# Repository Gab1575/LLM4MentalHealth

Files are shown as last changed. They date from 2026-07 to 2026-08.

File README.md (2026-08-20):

# LLM4MentalHealth

LLM4MentalHealth is a robotics project that explores how non-anthropomorphic social robots can support mental health and wellbeing. The robot embodies a flower that combines petal movement, color, and a dual-stage tendon-driven continuum stem into a single interactive platform.

## Project vision

The flower robot is designed to act as a non-verbal companion that can communicate emotion and intent through:

- five independently addressable petal LEDs,
- four petal-angle actuators,
- a motorized stem / continuum-style drive system,
- a ROS 2-based control interface for real-time command and monitoring.

### Physical layout summary

- Embedded controller: ESP32-based microcontroller running the firmware.
- Communication: Wi-Fi + micro-ROS bridge to a host computer.
- Operator interface: a Tkinter-based GUI and ROS 2 topics.
- Control: servo motors, N20 encoded gear motor, addressable RGB LED NeoPixels.

## Repository structure

- [README.md](README.md): project-level overview and architecture.
- [FullCode_ws](FullCode_ws): host-side ROS 2 workspace, GUI, and message definitions.
- [FullCodeMICROCONTROLLEr](FullCodeMICROCONTROLLEr): embedded firmware for the ESP32-based flower robot.
- [Testing](Testing): hardware and software experiments, prototypes, and validation sketches.
- [Construction](Construction): bill of materials and laser-cut sketches for the physical build.

## Software architecture

The system uses a split architecture:

- A host-side ROS 2 layer publishes high-level commands from the GUI, an optional kinematic solver, and perception nodes.
- A mux node merges those sources into a single authoritative command stream.
- A micro-ROS agent bridges that stream over Wi-Fi to the ESP32.
- The embedded firmware interprets the command stream and drives the robot’s motors, LEDs, and servos.

### Core control flow

1. A user manipulates the GUI, in either manual or kinematic mode.
2. The GUI publishes RobotCommand data to /manual_commands (and, in kinematic mode, bend targets to /kinematic_commands).
3. In kinematic mode, the continuum controller converts those bend targets into per-servo angles and publishes them to /kinematic_calculated_commands.
4. flower_mux selects manual or kinematic data based on /control_mode and publishes one merged RobotCommand to /flower_commands.
5. The micro-ROS agent forwards /flower_commands to the ESP32.
6. The ESP32 updates servo positions, LED colors, and motor target state, and reports debugging information back over /flower_debug.

## ROS node map

```mermaid
flowchart LR
    A["User / Operator"] --> B[flower_gui_node]
    B -->|/manual_commands| M[flower_mux_node]
    B -->|/kinematic_commands| K[continuum_controller_node]
    B -->|/control_mode| M
    K -->|/kinematic_calculated_commands| M
    M -->|/flower_commands| D[micro-ROS Agent]
    D --> E[ESP32 flower_node]
    E --> F[Servo Control]
    E --> G[LED Control]
    E --> H[N20 Motor Control]
    E -->|/flower_debug| J["Foxglove / Debug Tools"]
```

### ROS topics and roles

- /manual_commands, /kinematic_commands, /control_mode
  - Published by flower_gui_node; the raw manual/kinematic operator input and the active mode.

- /kinematic_calculated_commands
  - Published by continuum_controller_node; per-servo angles solved from the kinematic bend targets.

- /flower_commands
  - Custom message type: RobotCommand.
  - Published by flower_mux_node; the single merged command stream (servo angles, LED brightness, LED colors, N20 motor target state) that the embedded firmware actually receives.

- /flower_debug
  - Debug string topic published by the ESP32, used for troubleshooting and runtime telemetry.

### ROS-side components

- flower_gui_node
  - Tkinter-based operator dashboard.
  - Publishes to /manual_commands, /kinematic_commands, and /control_mode.

- continuum_controller_node
  - Kinematic solver; converts bend commands into antagonistic servo-pair angles.

- flower_mux_node
  - Mode-aware multiplexer; merges GUI and kinematic sources into /flower_commands.

- flower.launch.py
  - Launches the micro-ROS agent, Foxglove bridge, GUI, perception nodes, mux, and kinematic controller together.

For the full topic-level breakdown (including the vision/perception nodes), see [FullCode_ws](FullCode_ws).

## Notes

For deeper implementation detail, see the READMEs in the subprojects:

- [FullCode_ws](FullCode_ws)
- [FullCodeMICROCONTROLLEr](FullCodeMICROCONTROLLEr)
- [Construction](Construction)

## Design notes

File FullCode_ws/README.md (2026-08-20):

# FullCode_ws

This workspace is the host-side control stack for the flower robot. It includes the host GUI, ROS2 message definitions, smart command multiplexing, and vision-based position sensing.

## Purpose

The host workspace translates user intent and visual perception into a structured ROS2 command stream for the embedded flower controller. It also provides runtime launch orchestration for camera-based localization and face-tracking perception.

## High-level ROS2 Architecture

The control chain is split into four core domains:

1. **Host UI and command generation**
   - `flower_gui` publishes operator-selected servo, LED, and N20 values.
   - It also publishes kinematic goals and control mode state.

2. **Kinematic solving**
   - `controller` (`continuum_controller_node`) converts `(theta, phi)` bend commands from `/kinematic_commands` into per-servo antagonistic-pair angles.
   - It publishes the resulting `RobotCommand` to `/kinematic_calculated_commands`.

3. **Command multiplexing**
   - `flower_mux` merges GUI state with either manual or kinematic pose commands.
   - It publishes the final `RobotCommand` to `/flower_commands` for the micro-ROS bridge.

4. **Vision-based localization & perception**
   - `localization_tracker` detects red and blue target balls and publishes 3D points to `/vision/red_ball` and `/vision/blue_ball`. These are not currently consumed by any node (see Notes).
   - `face_tracker` publishes a lightweight point representing face pan/tilt angles to `/face_tracking_angles`.

5. **Hardware bridge**
   - `micro_ros_agent` bridges `/flower_commands` from ROS2 into the embedded firmware transport layer.
   - `foxglove_bridge` exposes ROS2 topics for debugging and visualization.

## Workspace files and packages

### Root files

- `flower.launch.py`
  - Launch description for the host stack.
  - Starts `micro_ros_agent`, `foxglove_bridge`, `flower_gui`, `face_tracker`, `localization_tracker`, `flower_mux`, and `continuum_controller`.

### ROS 2 package sources

- `src/flower_gui/`
  - Main host-side control GUI (`flower_gui_node`).
  - Publishes to `/manual_commands`, `/kinematic_commands`, and `/control_mode`.
  - Uses `flower_msgs.msg.RobotCommand` for manual/full-state commands.
  - Uses `std_msgs.msg.Float64MultiArray` for kinematic goal publication.
  - Uses `std_msgs.msg.String` for publishing the selected control mode.
  - Bundles guided breathing routines under `flower_gui/routines/` (e.g. `box_breathing.py`).

- `src/flower_mux/`
  - Smart multiplexer node (`flower_mux_node`).
  - Subscribes to `/manual_commands`, `/kinematic_calculated_commands`, and `/control_mode`.
  - Publishes the merged `RobotCommand` to `/flower_commands`.
  - Ensures time, LED, and N20 payload fields from the GUI remain present in kinematic mode.

- `src/flower_msgs/`
  - Defines the custom `RobotCommand` ROS2 message type.
  - Used by `flower_gui`, `flower_mux`, `controller`, and the embedded controller bridge.

- `src/controller/controller/continuum_controller_node.py`
  - Kinematic solver node. Subscribes to `/kinematic_commands` (`[theta1, phi1, theta2, phi2]`, degrees).
  - Converts each stage's bend into a pair of antagonistic servo angles and publishes `RobotCommand` to `/kinematic_calculated_commands`.
  - Vision-based (red/blue ball) feedback is not currently used by this node.

- `src/ros2-opencv-localization/`
  - Contains the `localization_tracker` node and a camera launch file.
  - Responsible for 3D ball localization from a connected USB camera.

- `src/ros2-opencv-face-tracker/`
  - Contains the face tracker node that publishes face pan/tilt offset angles.
  - Uses a second USB camera for live face detection.

- `src/uros/micro-ROS-Agent/`
  - Contains the micro-ROS agent package used by the host launch file.

## ROS2 Topic & Node Communication Tree

```text
[ Operator ]
      |
      v
flower_gui (host node)
  - publishes /manual_commands         (RobotCommand)
  - publishes /kinematic_commands      (Float64MultiArray)
  - publishes /control_mode            (String)
      |
      +----------------------------------------+
      v                                         v
continuum_controller_node                  flower_mux (host mux node)
  - subscribes /kinematic_commands         - subscribes /manual_commands
  - publishes /kinematic_calculated_commands - subscribes /kinematic_calculated_commands
      |                                       - subscribes /control_mode
      +-------------------------------------->|
                                                - publishes /flower_commands  (RobotCommand)
                                                    |
                                                    v
                                          micro_ros_agent (bridge)
                                                    |
                                                    v
                                    [ Embedded ESP32 / firmware ]

[ Vision & Perception ]
      |
      v
localization_tracker (vision node)
  - publishes /vision/red_ball         (PointStamped)
  - publishes /vision/blue_ball        (PointStamped)
  (not currently subscribed to by any node)

face_tracker (perception node)
  - publishes /face_tracking_angles    (Point)
```

## Simplified Architecture Diagram

```text
[ Operator ]
      |
      v
flower_gui
  publishes /manual_commands  + /kinematic_commands + /control_mode
      |
      +--> continuum_controller_node
      |      subscribes /kinematic_commands
      |      publishes /kinematic_calculated_commands
      |
      v
flower_mux
  selects mode -> merges GUI state with calculated kinematic commands
      |
      v
/flower_commands  ---> micro_ros_agent ---> embedded firmware

[ Vision ]
      |
      +--> localization_tracker
      |      publishes /vision/red_ball
      |               /vision/blue_ball
      |      (USB camera sees red and blue target balls; unused downstream for now)
      |
      +--> face_tracker
             publishes /face_tracking_angles
             (separate camera, face pan/tilt signal)
```

## Topic semantics and data flow

### `/manual_commands` (RobotCommand)
- Published by `flower_gui` continuously.
- Contains the full manual output state from the GUI, including:
  - `servo_angles[4]`
  - `servo_time[4]`
  - `n20_pwm`
  - `n20_target_rotations`
  - `n20_zero`
  - `led_colours_hex[5]`
  - `led_colours_brightness[5]`
- Used as the authoritative state cache in `flower_mux` for both manual and kinematic modes.

### `/kinematic_commands` (Float64MultiArray)
- Published by `flower_gui` from the kinematic control panel.
- Carries `[theta1, phi1, theta2, phi2]` (degrees): bend magnitude and bend-plane direction for each of the two continuum stages.
- Consumed by `continuum_controller_node`.

### `/kinematic_calculated_commands` (RobotCommand)
- Published by `continuum_controller_node`.
- Carries the final per-servo angles (`servo_angles[4]`, all four indices driven) after converting each stage's `(theta, phi)` into an antagonistic servo pair.
- Consumed by `flower_mux`, which merges it with the GUI's cached LED/N20/time state when in kinematic mode.

### `/control_mode` (String)
- Published by `flower_gui` when the UI mode changes.
- Values are `manual` or `kinematic`.
- Controls whether `flower_mux` forwards raw manual state or uses the kinematic-calculated command path.

### `/flower_commands` (RobotCommand)
- Final merged command stream.
- Published by `flower_mux` to the hardware bridge.
- This is the topic the embedded controller ultimately receives via `micro_ros_agent`.

### `/vision/red_ball` and `/vision/blue_ball` (PointStamped)
- Published by `localization_tracker`.
- Each message carries the 3D position of a color-marked ball in camera coordinates.
- Not currently subscribed to by any node; reserved for future vision-based closed-loop control.

### `/face_tracking_angles` (Point)
- Published by `face_tracker`.
- `x` and `y` carry pan and tilt error angles in degrees.
- Intended for face-aligned perception or downstream attention control.

## Physical sensor mapping

### Localization camera
- The `localization_tracker` node uses OpenCV to capture frames from a USB camera.
- It detects red and blue balls using HSV color segmentation.
- It converts ball pixel measurements into 3D coordinates using camera intrinsics (`fx`, `fy`, `cx`, `cy`).
- The two balls define the flower head geometry; this data is not currently consumed by the controller.

### Face-tracker camera
- The `face_tracker` node reads from an attached camera and detects the closest face using RetinaFace.
- It publishes a minimal steering signal as pan/tilt error angles.
- This is useful for adding a second perception channel for attention-based interaction.

### Embedded hardware connection
- `micro_ros_agent` runs as a bridge node in `flower.launch.py`.
- It exposes host-side `RobotCommand` traffic to the ESP32/microcontroller transport layer.
- The controller receives the final merged `/flower_commands` message rather than raw GUI-only messages.

## File summary

### `src/flower_gui/`
- Primary host control UI (`flower_gui_node`).
- Publishes manual and kinematic command streams.
- Saves GUI state to `~/flower_gui_settings.json`.
- Uses `flower_msgs.msg.RobotCommand`.

### `src/flower_mux/`
- Smart mode-dependent message multiplexer (`flower_mux_node`).
- Ensures kinematic mode keeps the GUI's latest LED and N20 state.
- Sends one coherent `RobotCommand` stream to hardware.

### `flower.launch.py`
- Host-side launch orchestration.
- Starts the GUI, the vision nodes, the kinematic controller, `flower_mux`, `micro_ros_agent`, and `foxglove_bridge` together.

### `src/flower_msgs/msg/RobotCommand.msg`
- Defines the host-to-hardware command schema.
- Ensures consistent message structure across GUI, mux, controller, and firmware.

### `src/controller/controller/continuum_controller_node.py`
- Kinematic solver: converts `(theta, phi)` bend commands into antagonistic servo-pair angles.
- Subscribes to `/kinematic_commands`; publishes `/kinematic_calculated_commands`.

### `src/ros2-opencv-localization/`
- Contains the camera-based localization tracker.
- Publishes `/vision/red_ball` and `/vision/blue_ball`.

### `src/ros2-opencv-face-tracker/`
- Contains the face tracker node.
- Publishes `/face_tracking_angles`.

## Notes

- `flower_gui`, `flower_mux`, and `controller` are all standard `ament_python` packages under `src/`, built with `colcon build` and run via `ros2 run <package> <executable>` (or through `flower.launch.py`).
- The root launch file currently starts the perception and control bridge nodes, but the embedded controller node may require a separate launch or firmware-side startup.

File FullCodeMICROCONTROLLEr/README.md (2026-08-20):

# FullCodeMICROCONTROLLEr

This project is the embedded firmware for the flower robot. It runs on an ESP32 controller and is responsible for receiving commands from ROS 2, driving the physical actuators, and maintaining the robot’s real-time behavior.

## Purpose

The firmware implements the robot’s low-level control layer. Its responsibilities are:

- establishing Wi-Fi connectivity for micro-ROS communication,
- receiving RobotCommand payloads from the host workstation,
- updating the servo-driven petal positions,
- driving petal LEDs with color and brightness values,
- controlling the N20 motor and encoder-based position loop,
- publishing debug telemetry back over ROS for troubleshooting.

## High-level architecture

The firmware is organized around a simple control loop:

1. Initialize Wi-Fi and the micro-ROS transport.
2. Initialize the hardware subsystems: LEDs, servos, and motor.
3. Wait for incoming RobotCommand messages.
4. Apply the new command state each loop iteration.
5. Update hardware outputs and publish debug information.

## Folder and file overview

### Root files

- platformio.ini
  - PlatformIO configuration for building and uploading the firmware.
  - Defines dependencies and board settings for the ESP32 target.

### include/

The include directory contains shared declarations and hardware abstractions.

- MicroRos.h
  - Central header for ROS-related globals, data structures, and function declarations.
  - Defines the shared Data struct that holds servo, LED, and N20 command state.

- N20.h
  - Pin definitions, constants, and function declarations for the N20 motor.

- petal_lights.h
  - LED subsystem declarations.

- servo_control.h
  - Servo subsystem declarations and constants.

- MicroRosWifiCredentialsEXAMPLE.h
  - Example template for storing Wi-Fi credentials locally.

### src/

The source directory contains the actual implementation of the firmware logic.

- main.cpp
  - Main application entry point.
  - Performs startup initialization and runs the main control loop.

- MicroRos.cpp
  - Implements Wi-Fi setup, micro-ROS initialization, message subscription, and debug publishing.

- servo_control.cpp
  - Implements servo initialization and motion control.

- petal_lights.cpp
  - Implements LED rendering and color updates.

- N20.cpp
  - Implements encoder-based position tracking and motor control.

## Deep dive by file

### src/main.cpp

This is the orchestrator for the firmware.

Responsibilities:

- initializes serial logging,
- sets up Wi-Fi,
- initializes LED control,
- initializes servo control,
- initializes the N20 motor,
- calls the micro-ROS setup routine,
- enters the main loop where each subsystem is refreshed from the latest command state.

Main loop behavior:

- processes pending ROS callbacks,
- updates each petal LED from the current command data,
- applies the latest servo target positions,
- updates the N20 motor position estimate and control loop,
- shows the new LED output.

### src/MicroRos.cpp

This file is the embedded ROS bridge.

Its main functions are:

- WiFiSetup()
  - Connects the ESP32 to Wi-Fi.
  - Resolves the host agent hostname using mDNS.
  - Configures the micro-ROS transport.

- MicroRosSetup()
  - Initializes the ROS 2 node, executor, subscription, and debug publisher.
  - Subscribes to the /flower_commands topic.

- subscription_callback()
  - Receives incoming RobotCommand data.
  - Copies the servo angles, N20 target, N20 speed, LED colors, and brightness values into the shared global data struct.

- send_debug()
  - Formats and publishes debug strings to the /flower_debug topic.

This module is the critical link between the host system and the physical hardware.

### src/servo_control.cpp

This file manages the stem's tendon-driven bend, via the four servos that remain
after the neck joint (the former servo 0) was removed from the design.

Key responsibilities:

- initialize the PCA9685 servo driver over I2C,
- track each servo's current/target pulse and move it smoothly (S-curve eased) toward
  the target over a commanded time window,
- expose absolute angle targets (-90 to 90 degrees) to the rest of the firmware.

Servos 0-3 map directly to PCA9685 channels 0-3 (`ServoState.hardwareIndex`).

### src/petal_lights.cpp

Responsibilities:

- create and manage an LED array,
- update individual petal colors from incoming command values,
- scale each LED’s brightness,
- push the color values to the physical LEDs.

The implementation uses FastLED and a CRGB buffer. It updates the LED state in memory first and only shows the result once the full frame is prepared.

### src/N20.cpp

This file controls the N20 geared motor and its feedback loop.

Responsibilities:

- configure motor control pins,
- initialize encoder input pins,
- attach an interrupt service routine for encoder pulses,
- track motor position in rotations,
- apply a simple control loop that moves the motor toward the commanded target.

Key functions:

- n20EncoderISR()
  - Reads the encoder state and updates the tick count.

- n20MotorBegin()
  - Initializes the hardware and synchronizes the internal position estimate with the commanded target.

- n20MotorSetSpeed()
  - Applies PWM speed control.

- n20MotorSetDirection()
  - Sets the motor direction through the H-bridge pins.

- n20MotorControl()
  - Compares the current position to the target and drives the motor until it is within tolerance.

- n20MotorPosition()
  - Converts encoder ticks into a position estimate for the control loop.

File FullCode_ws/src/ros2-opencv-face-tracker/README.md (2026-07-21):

# ROS 2 OpenCV Face Tracker: Zero-Latency Edge Perception 





A hyper-optimized, real-time computer vision node for ROS 2 that achieves zero-latency face tracking by bypassing standard middleware serialization bottlenecks.

## 📖 Project Overview

In standard ROS 2 perception pipelines, relying on generic camera drivers and `CvBridge` introduces severe frame-rate drops on standard edge hardware (often sub-1 FPS). This is caused by the heavy network serialization overhead of translating massive raw image matrices into ROS network messages and back again.

This package re-architects the perception pipeline into a lightweight, all-in-one edge node. By utilizing OpenCV's direct hardware interface (`cv2.VideoCapture`) to pull frames straight into the processing script, this node keeps heavy image matrices entirely off the ROS local network. The result is flawless, real-time bounding box tracking that leaves maximum CPU overhead available for downstream robotic control.

## ✨ Key Features

* **Zero-Latency Processing:** Bypasses `usb_cam` and `CvBridge` serialization, reading the hardware stream directly.
* **Optimized Haar Cascades:** Fine-tuned detection parameters (`scaleFactor=1.3`, `minNeighbors=5`) to maximize frames per second without sacrificing accuracy.
* **Dynamic Contrast Adjustment:** Integrates CLAHE (Contrast Limited Adaptive Histogram Equalization) to maintain robust tracking in poor or uneven lighting conditions.
* **Native GUI Rendering:** Utilizes lightweight `cv2.imshow` native windows instead of heavy ROS debugging GUIs (like `rqt`) to eliminate rendering bottlenecks.

## ⚙️ System Requirements

* **OS:** Ubuntu 22.04 LTS
* **Middleware:** ROS 2 Humble Hawksbill
* **Dependencies:** Python 3, OpenCV (`python3-opencv`), `cv_bridge`, `sensor_msgs`
* **Hardware:** Any standard USB Web Camera (tested on `/dev/video*`)

## 🛠️ Installation & Build Instructions

1. **Clone the repository into your ROS 2 workspace:**
   ```bash
   cd ~/your_ws/src
   git clone [https://github.com/abinaabey2006/ros2-opencv-face-tracker.git](https://github.com/abinaabey2006/ros2-opencv-face-tracker.git)

    Navigate to the workspace root and resolve dependencies:
    Bash

    cd ~/your_ws
    rosdep install --from-paths src --ignore-src -r -y

    Build the package:
    Bash

    colcon build --packages-select face_tracker

    Source the workspace:
    Bash

    source install/setup.bash

🚀 Usage

To launch the real-time tracking node, ensure your USB camera is plugged in and run:
Bash

ros2 run face_tracker face_tracker

A native OpenCV window will open displaying the real-time camera feed with a tracking bounding box.

    Note: To cleanly exit the node and release the camera hardware, press Ctrl+C in the terminal.

🔮 Future Scope: Autonomous Motion Control

The current architecture successfully isolates and tracks targets at the edge. The immediate next step for this project is to publish the (x, y) center coordinates of the detected bounding box as lightweight geometry_msgs/Point or geometry_msgs/Pose data.

This will act as the foundational perception data to drive autonomous motion control systems—allowing physical platforms (like a TurtleBot 3 in Gazebo) to execute trajectory adjustments to keep the target dynamically centered in its field of view.

Built by Abina Abey.

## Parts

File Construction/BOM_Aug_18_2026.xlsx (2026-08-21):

FlowerAssembly
Working BOM | as of August 18, 2026 at 6:11:39 PM UTC
 | Gavin.Bayley@queensu.ca
INDIVIDUAL COUNTS |  |  |  |  | TOTAL COUNTS
Section | Part Name | Description | Quantity | Material | Part Name | Description | Quantity | Material
Flower Head |  |  |  |  | 0.1uF Cap | Small Cap next to ESP32 Power Pins | 1 | Electrical Component
 | BaseV3 | Central Component | 1 | Resin (MSLA Printer) | 1.2mm Spring Steel Rod | Back Bone | 1 | Spring Steel | https://www.amazon.ca/BBYPP-Straight-Steeless-Assortment-Different/dp/B09DKG7MNB
 | CenterRingV3 | 2 Bodies, Structure & Shell. Print seperatly. Holes drilled to 2mm for Pins | 1 | Resin (MSLA Printer) | 1000uF Cap | Large Cap next to power in of Perfboard | 1 | Electrical Component
 | BlueBall | For Localization | 1 | PLA (FDM Printer) | 3 wire conductor | 3 wire conductor for LED's in ft | 1 | Electrical Component | https://www.digikey.ca/en/products/detail/tensility-international-corp/30-00495/13617532?gclsrc=aw.ds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
 | 3mmx50mm rod | Cut Stainless Steel Rod, Supports Balls | 2 | Steel | 3x12mm Rod | Pins for OuterBearings | 8 | Steel | https://www.amazon.ca/Awclub-Stainless-Industry-Working-Hobbies/dp/B0CN79F664?sp_csd=d2lkZ2V0TmFtZT1zcF9hdGY
 | FlowerPetal | Flower Petals, Holes drilled to 2mm | 5 | Resin (MSLA Printer) | 3x18mm Rod | Holds assembly Together and supports Bearing | 12 | Steel
 | RedBall | For Localization | 1 | PLA (FDM Printer) | 3x50mm rod | Cut Stainless Steel Rod, Supports Balls | 2 | Steel
 | 4x30mm rod | Cut Stainless Steel Rod, Centering Rods for CentreRingV3 | 3 | Steel | 3x8mm Rod | Pins for inner bearings | 8 | Steel
 | ConnectingBracketV3 | Connecting Rods Between Flower Petal and Center Ring. Holes Drilled to 2mm for Pins | 5 | Resin (MSLA Printer) | 4x30mm rod | Cut Stainless Steel Rod, Centering Rods for CentreRingV3 | 3 | Steel | https://www.amazon.ca/PATIKIL-Marine-Stainless-Support-Shelves/dp/B0FWKMY94L
 | 4x6mm Brass Sleeve | Sleeve for reduced friction on centering rods | 3 | Brass | 4x6mm Brass Sleeve | Sleeve for reduced friction on centering rods | 3 | Brass | https://www.amazon.ca/MECCANIXITY-Bearings-Self-Lubricating-Movements-Machinery/dp/B0FFS8BSXX
 | M6x6 Heat Set Insert | Placed in CenterRingV3 | 1 | Brass | 7 Conductor Cable | Wiring between flower head and pot (ft) | 2 | Electrical Component | https://www.digikey.ca/en/products/detail/tensility-international-corp/30-00516/24671340?gclsrc=aw.ds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
 | Socket Head Cap Screw M1.6x0.35 x 4 | N20 Motor Screws | 2 | Steel | Aluminum Cable Ferrules, 0.02" | Crimps to tie Tendon Ends | 16 | Aluminum | https://www.amazon.ca/uxcell-Aluminum-Crimping-Ferrules-Ferrule/dp/B0F8R57K5M
 | MicroGearmotor v3 | 300RPM 6V N20 GearMotor | 1 | Brass, Soft Yellow | Ball and Socket | Middle Joints | 6 | Resin (MSLA Printer)
 | ws2812 5050 led | LED's for the Flower Petals | 5 | Electrical Component | Ball and Socket - 4mm | Lower Joints Gradually Grow to connection with Base | 1 | Resin (MSLA Printer)
 | 3 wire conductor | 3 wire conductor for LED's in ft | 1 | Electrical Component | Ball and Socket - 5mm | "" | 1 | Resin (MSLA Printer)
 | JST1.5 6 pin connector male | Connector for N20 Motor | 1 | Electrical Component | Ball and Socket - 6mm | "" | 1 | Resin (MSLA Printer)
 | JST1.5 3 pin connector | Male and Female for connector for LED string | 1 | Electrical Component | Ball and Socket - 7mm | "" | 1 | Resin (MSLA Printer)
 | Pin | Cut 2x8mm Stainless Steel Rod. Attaches Connecting Rod to both Petals and CenterRing | 10 | Steel | Ball and Socket - 8mm | "" | 1 | Resin (MSLA Printer)
Stem |  |  |  |  | Ball and Socket Top | Top Piece | 1 | Resin (MSLA Printer)
 | Ball and Socket | Middle Joints | 6 | Resin (MSLA Printer) | Barrel Jack | Power Jack | 1 | Electrical Component
 | Ball and Socket Top | Top Piece | 1 | Resin (MSLA Printer) | BarrelJackMount | Part to hold the barrel Jack | 1 | PLA (FDM Printer)
 | Ball and Socket - 4mm | Lower Joints Gradually Grow to connection with Base | 1 | Resin (MSLA Printer) | BasePlate | Laser cut base plate | 1 | 3mm Acrylic | https://www.amazon.ca/dp/B088LM5PCG?amp=
 | Ball and Socket - 7mm | "" | 1 | Resin (MSLA Printer) | BaseV3 | Central Component | 1 | Resin (MSLA Printer)
 | Ball and Socket - 8mm | "" | 1 | Resin (MSLA Printer) | Bearing | Bearings | 24 | Steel | https://www.amazon.ca/Saipor-693ZZ-Bearings-Bearing-Miniature/dp/B0DHNJ51PH?sp_csd=d2lkZ2V0TmFtZT1zcF9hdGY
 | Ball and Socket - 5mm | "" | 1 | Resin (MSLA Printer) | Binding Head Screw M3x5 | Screws to affix SpoolV2 to Servo Horn | 2 | Steel
 | Ball and Socket - 6mm | "" | 1 | Resin (MSLA Printer) | BlueBall | For Localization | 1 | PLA (FDM Printer)
 | 1.2mm Spring Steel Rod | Back Bone | 1 | Spring Steel | CenterRingV3 | 2 Bodies, Structure & Shell. Print seperatly. Holes drilled to 2mm for Pins | 1 | Resin (MSLA Printer)
 | Stainless Steel Cable, 1x7, 0.021" | Tendons. Each approx 1.5ft. | 8 | Steel | CentreSupport | 3D Printed Center Support | 1 | PLA (FDM Printer)
 | Aluminum Cable Ferrules, 0.02" | Crimps to tie Tendon Ends | 16 | Aluminum | ConnectingBracketV3 | Connecting Rods Between Flower Petal and Center Ring. Holes Drilled to 2mm for Pins | 5 | Resin (MSLA Printer)
Base |  |  |  |  | ESP-32 | Microcontroller | 1 | Electrical Component | https://www.amazon.ca/ESP-WROOM-32-NodeMCU-Bluetooth-Development-Microcontroller/dp/B0CHBMFJBQ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
Servo Assembly (x4) |  |  |  |  | ElectronicsPlate | Laser Cut plate that Electronics mount to | 1 | 3mm Acrylic
 | ServoPlate | Plates that Servos Mount on | 1 | 3mm Acrylic | FlowerPetal | Flower Petals, Holes drilled to 2mm | 5 | Resin (MSLA Printer)
 | Nylon Washer - M2.5 | Nylon Washers For Spring and ServoTensioner Affixment | 4 | Nylon | HeatSetInsert-M2.5x2.5 | To affix ServoPlate to ServoTensioner | 2 | Brass
 | Nylon Washer - M3 | Nylon Washers for Servo Affixment | 4 | Nylon | HeatSetInsert-M2.5x4 | Insert for Spring | 1 | Brass
 | Stainless Steel Washer - M3 | Steel Washers for Servo Affixment | 4 | Steel | HeatSetInsert-M2.5x6 | Inserts for Mounting | 3 | Brass
 | ServoTensioner | Component that allows for the assembly to be tensioned | 1 | PLA (FDM Printer) | HeatSetInsert-M3x8 | Heat Set Insert for Servo Tensioner | 1 | Brass
 | HeatSetInsert-M2.5x2.5 | To affix ServoPlate to ServoTensioner | 2 | Brass | JST1.5 3 Pin Connector | Male and Female for connector for LED string | 1 | Electrical Component
 | SpoolV2 | Wire Spool | 1 | Resin (MSLA Printer) | JST1.5 6 pin connector male | Connector for N20 Motor | 1 | Electrical Component
 | ServoHorn | Metal Circular Servo Horn Included with Servos | 1 | Steel | L293D H bridge Motor Driver | Motor Driver for N20 Motor | 1 | Electrical Component | https://www.digikey.ca/en/products/detail/stmicroelectronics/L293D/634700?gclsrc=aw.ds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
 | Spring-4mmx10 | Spring for Tensioning | 1 | Steel | M2.5 Nut | Nut to affix Spring | 21 | Steel
 | ServoMotorBrushless | Servo Motor | 1 | Electrical Component | M2.5 Nylon Washer | Nylon Washers For Spring and ServoTensioner Affixment | 39 | Nylon | https://www.amazon.ca/1205PCS-Nylon-Flat-Washers-Assortment/dp/B0FRMRXMQR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
 | Socket Head Screw - M3x0.5 x 12 | Screws to Fasten Servo Motor | 4 | Steel | M3 Nut | Nuts to Fasten Servo Motor | 11 | Steel
 | Hexagon Nut - M3 x 0.5 | Nuts to Fasten Servo Motor | 4 | Steel | M3 Nylon Washer | Nylon Washers for Servo Affixment | 22 | Nylon
 | HeatSetInsert-M3x8 | Heat Set Insert for Servo Tensioner | 1 | Brass | M6x6 Heat Set Insert | Placed in CenterRingV3 | 1 | Brass
 | Socket Head Screw - M2.5x0.45 x 6 | Screws to Fasten Servo Tensioner and Spring | 3 | Steel | MicroGearmotor v3 | 300RPM 6V N20 GearMotor | 1 | Brass, Soft Yellow
 | Hexagon Nut - M2.5 x 0.45 | Nut to affix Spring | 1 | Steel | MidBearingMount-Bottom | Plate for middle sections | 3 | 3mm Acrylic
 | Binding Head Screw - M3x5 | Screws to affix SpoolV2 to Servo Horn | 2 | Steel | MidBearingMount-Mid | Plate that has bearing pin slots for middle section | 1 | 3mm Acrylic
 | Socket Head Screw - M3x0.5 x 5 | Screw to affix ServoHorn to ServoMotor | 1 | Steel | MidPlate | Lower Assembly Plate | 1 | 3mm Acrylic
Side Supports (x4) - 1 Modified |  |  |  |  | MidPlateShell | Outer Acrylic | 3 | 3mm Acrylic
 | HeatSetInsert-M2.5x6 | Inserts for Mounting | 3 | Brass | MidPlateShellBearing | Outer Acrylic with bearing shaft holes | 1 | 3mm Acrylic
 | HeatSetInsert-M2.5x4 | Insert for Spring | 1 | Brass | OuterShell | Case For Flower Pot | 1 | PLA (FDM Printer)
 | SideSupports | Support to hold Servo Assemblies | 1 | PLA (FDM Printer) | PCA9685 | Servo Motor Controller | 1 | Electrical Component | https://www.amazon.ca/PCA9685-Automation-Robotics-Development-Generator/dp/B0G2SXDK4X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
 | SideSupportWire | Support to hold Servo Assemblies -> 1x needed for wire passthrough | 1 | PLA (FDM Printer) | Perfboard | Mounts Motor Driver and ESP32 and gives pinouts/ins for components | 1 | Perfboard
 | Socket Head Screw M2.5x0.45 x 4 | Screw to affix Spring | 1 | Steel | Pin | Cut 2x8mm Stainless Steel Rod. Attaches Connecting Rod to both Petals and CenterRing | 10 | Steel
Plates Assembly (x1) |  |  |  |  | Pinhole Camera | Ultra Tiny USB Webcam Camera with GC0307 Sensor | 2 | Electrical Component | https://www.digikey.ca/fr/products/detail/adafruit-industries-llc/5733/21839820
 | MidBearingMount-Mid | Plate that has bearing pin slots for middle section | 1 | 3mm Acrylic | RedBall | For Localization | 1 | PLA (FDM Printer)
 | TopPlate | Top Plate | 1 | 3mm Acrylic | Rollers | Horizontal bearing sleeves | 8 | PLA (FDM Printer)
 | 3x18mm Rod | Holds assembly Together and supports Bearing | 12 | Steel | ServoHorn | Metal Circular Servo Horn Included with Servos | 1 | Steel
 | 3x8mm Rod | Pins for inner bearings | 8 | Steel | ServoMotorBrushless | Servo Motor | 1 | Electrical Component | https://www.digikey.ca/en/products/detail/dfrobot/SER0062/18069235?gclsrc=aw.ds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
 | Bearing | Bearings | 24 | Steel | ServoPlate | Plates that Servos Mount on | 1 | 3mm Acrylic
 | SmallBearingSleeve | Vertical Bearing Sleeves | 16 | Steel | ServoTensioner | Component that allows for the assembly to be tensioned | 1 | PLA (FDM Printer)
 | MidBearingMount-Bottom | Plate for middle sections | 3 | 3mm Acrylic | SideSupportWire | Support to hold Servo Assemblies -> 1x needed for wire passthrough | 1 | PLA (FDM Printer)
 | MidPlate | Lower Assembly Plate | 1 | 3mm Acrylic | SideSupports | Support to hold Servo Assemblies | 1 | PLA (FDM Printer)
 | 3x12mm Rod | Pins for OuterBearings | 8 | Steel | SmallBearingSleeve | Vertical Bearing Sleeves | 16 | Steel
 | MidPlateShell | Outer Acrylic | 3 | 3mm Acrylic | Socket Head Screw M1.6x4 | N20 Motor Screws | 2 | Steel
 | MidPlateShellBearing | Outer Acrylic with bearing shaft holes | 1 | 3mm Acrylic | Socket Head Screw M2.5x4 | Screw to affix Spring | 1 | Steel
 | Rollers | Horizontal beraing sleeves | 8 | PLA (FDM Printer) | Socket Head Screw M2.5x6 | Screws to Fasten Servo Tensioner and Spring | 3 | Steel
 | Socket Head Screw M3x0.5 x 25 | Outer Assembly Screws | 4 | Steel | Socket Head Screw M2.5x8 | misc screws | 19 | Steel
 | Nylon Washer M3 | Nylon Washers | 14 | Nylon | Socket Head Screw M3x12 | Screws to Fasten Servo Motor | 4 | Steel
 | Nut M3 x 0.5 | Nuts | 7 | Steel | Socket Head Screw M3x20 | Inner Mid Plate Screws | 3 | Steel
 | Pinhole Camera | Ultra Tiny USB Webcam Camera with GC0307 Sensor | 1 | Electrical Component | Socket Head Screw M3x25 | Outer Assembly Screws | 4 | Steel
 | Socket Head Screw M3x0.5 x 20 | Inner Mid Plate Screws | 3 | Steel | Socket Head Screw M3x30 | Tensioning Screws | 4 | Steel
Electronrics Assembly |  |  |  |  | Socket Head Screw M3x5 | Screw to affix ServoHorn to ServoMotor | 1 | Steel
 | Perfboard | Mounts Motor Driver and ESP32 and gives pinouts/ins for components | 1 | Perfboard | SpoolV2 | Wire Spool | 1 | Resin (MSLA Printer)
 | 1000uF Cap | Large Cap next to power in of Perfboard | 1 | Electrical Component | Spring-4mmx10 | Spring for Tensioning | 1 | Steel
 | 0.1uF Cap | Small Cap next to ESP32 Power Pins | 1 | Electrical Component | Stainless Steel Cable, 1x7, 0.021" | Tendons. Each approx 1.5ft. | 8 | Steel
 | ESP-32 | Microcontroller | 1 | Electrical Component | Stainless Steel Washer - M3 | Steel Washers for Servo Affixment | 4 | Steel
 | L293D H bridge Motor Driver | Motor Driver for N20 Motor | 1 | Electrical Component | Standoff m2.5x24mm | Flower Pot Legs | 4 | Plastic
 | ElectronicsPlate | Laser Cut plate that Electronics mount to | 1 | 3mm Acrylic | Standoff m2.5x8mm | Standoff between base plate and electronics plate | 1 | 3mm Acrylic
 | PCA9685 | Servo Motor Controller | 1 | Electrical Component | TopPlate | Top Plate | 1 | 3mm Acrylic
 | BarrelJackMount | Part to hold the barrel Jack | 1 | PLA (FDM Printer) | ws2812 5050 led | LED's for the Flower Petals | 5 | Electrical Component | https://www.digikey.ca/en/products/detail/w%C3%BCrth-elektronik/1315050930002/22677876
 | Barrel Jack | Power Jack | 1 | Electrical Component
 | Standoff m2.5x24mm | Flower Pot Legs | 4 | Plastic
 | Standoff m2.5x8mm | Standoff between base plate and electronics plate | 1 | 3mm Acrylic
 | M2.5 Nut | Misc nuts | 13 | Steel
 | M2.5 Nylon Washer | Misc Washers | 13 | Nylon
 | M.25x8 Socket Head Screw | misc screws | 7 | Steel
MISC
 | Nylon Washer M2.5 | Misc Nylong Washers | 22 | Nylon
 | Socket Head Screw - M2.5x0.45 x 8 | Misc Screws | 12 | Steel
 | CentreSupport | 3D Printed Center Support | 1 | PLA (FDM Printer)
 | Nylon Washer M3 | Washers for tensioning Screws | 4 | Nylon
 | 7 Conductor Cable | Wiring between flower head and pot (ft) | 2 | Electrical Component
 | OuterShell | Case For Flower Pot | 1 | PLA (FDM Printer)
 | BasePlate | Laser cut base plate | 1 | 3mm Acrylic
 | Socket Head Screw - M3x0.5 x 30 | Tensioning Screws | 4 | Steel
 | Nut M2.5 | Nuts | 7 | Steel
 | Pinhole Camera | Ultra Tiny USB Webcam Camera with GC0307 Sensor | 1 | Electrical Component

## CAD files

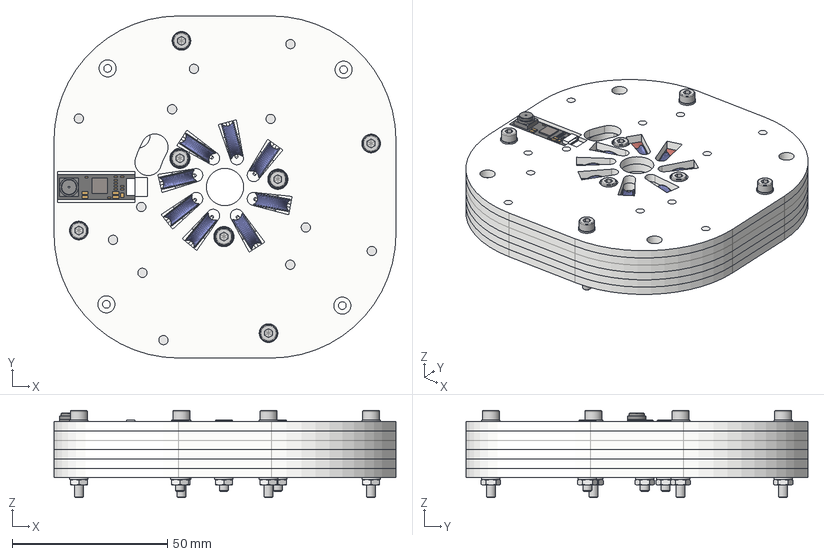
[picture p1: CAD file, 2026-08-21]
Construction/Fusion360Export/Current/Bases/BaseV7/Assemblies/PlatesAssembly_v33.step
110.0 x 110.0 x 28.0 mm
3x18mm Rod x 12
TopPlate
MidBearingMount-Mid
3x8mm Rod x 9
BearingSleeve x 16
MidBearingMount-Bottom x 3
MidPlate
MidPlateShell x 3
MidPlateShellBearing
3x10mm Rod x 8
Bearing_9
BearingSleeve_1 x 8
Bearing_10
Bearing_11
Bearing_12
Bearing_13
Bearing_14
Bearing_15
Bearing_16
Bearing_17
Bearing_18
Bearing_19
Bearing_20
Bearing_21
Bearing_22
Bearing_23
Bearing_24
BW BS 4320 - M3 E Steel 100 HV Plain x 14
BSHCS ASME B18.3.1M - M3x0.5 x 25 Steel Grade 2 Plain x 4
DIN 439-2 - M3 x 0.5 Steel 6 Plain x 7
BSHCS ASME B18.3.1M - M3x0.5 x 20 Steel Grade 2 Plain x 3
SmallBearingSleeve x 16
Ultra Tiny USB Camera with GC0307 Sensor

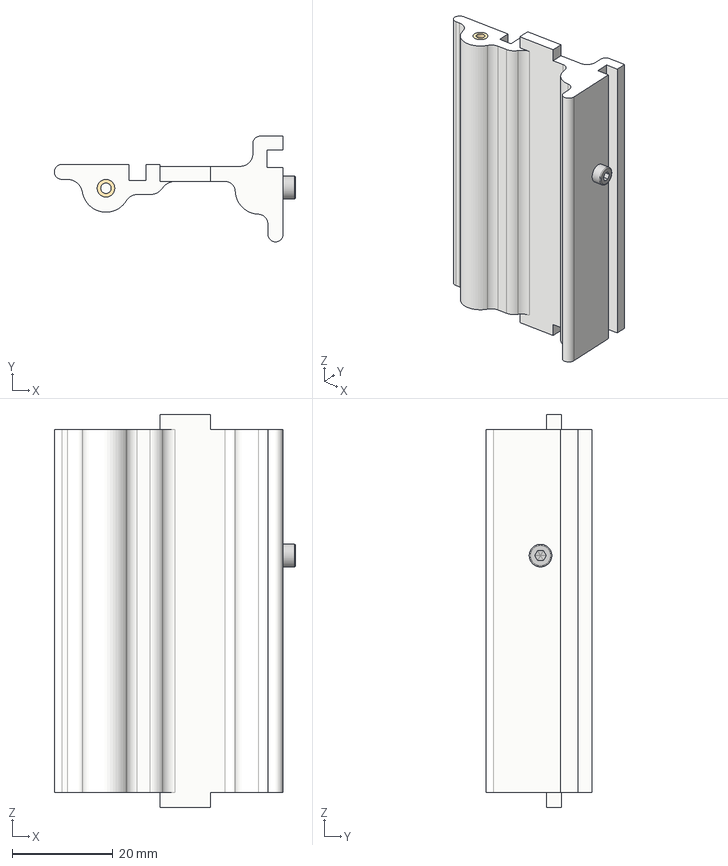
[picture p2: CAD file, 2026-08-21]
Construction/Fusion360Export/Current/Bases/BaseV7/Assemblies/SlideSupportAssembly_v5.step
47.9 x 21.0 x 78.0 mm
HeatSetInsert-M2.5x6 x 3
SlideSupports
HeatSetInsert-M2.5x4
BSHCS ASME B18.3.1M - M2.5x0.45 x 4 Steel Grade 2 Plain

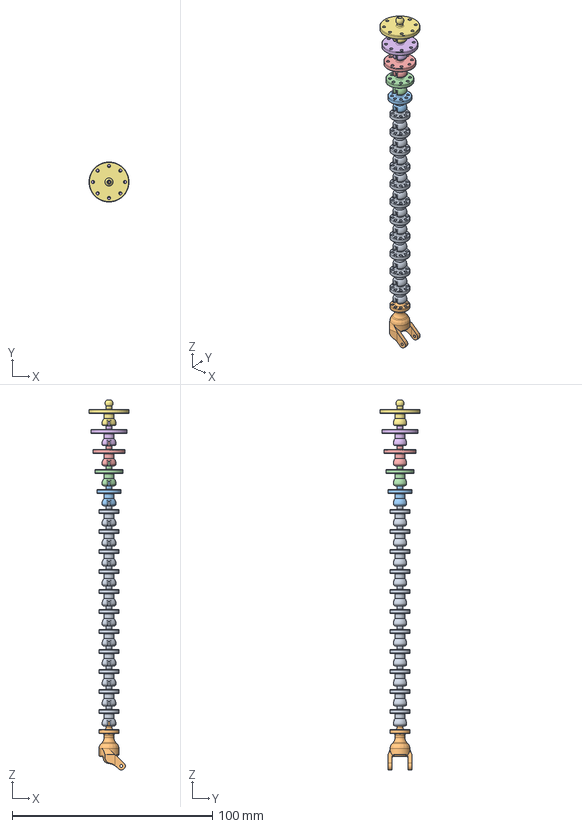
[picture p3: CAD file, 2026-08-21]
Construction/Fusion360Export/Current/Stems/ContinuumStemV4/Assembly_v6.step
20.0 x 20.0 x 184.9 mm
Ball and Socket x 11
Ball and Socket Top
Ball and Socket - 4mm
Ball and Socket - 5mm
Ball and Socket - 6mm
Ball and Socket - 7mm
Ball and Socket - 8mm

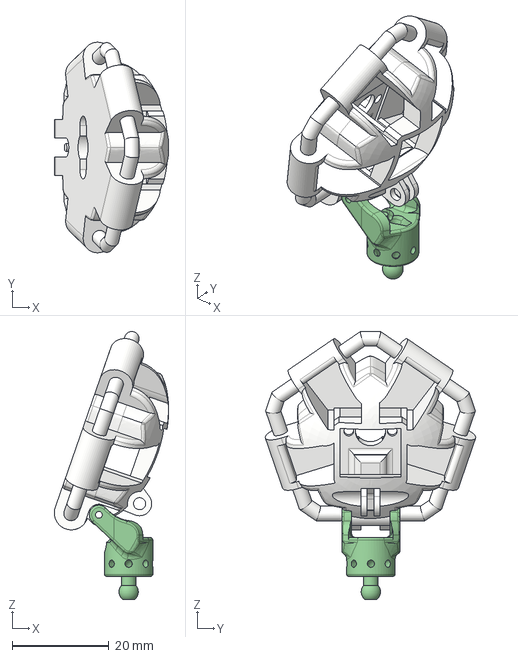
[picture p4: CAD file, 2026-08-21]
Construction/Fusion360Export/Current/Stems/ContinuumStemV4/TopAssembly_v10.step
23.6 x 43.5 x 55.4 mm
Ball and Socket Top
BaseV3

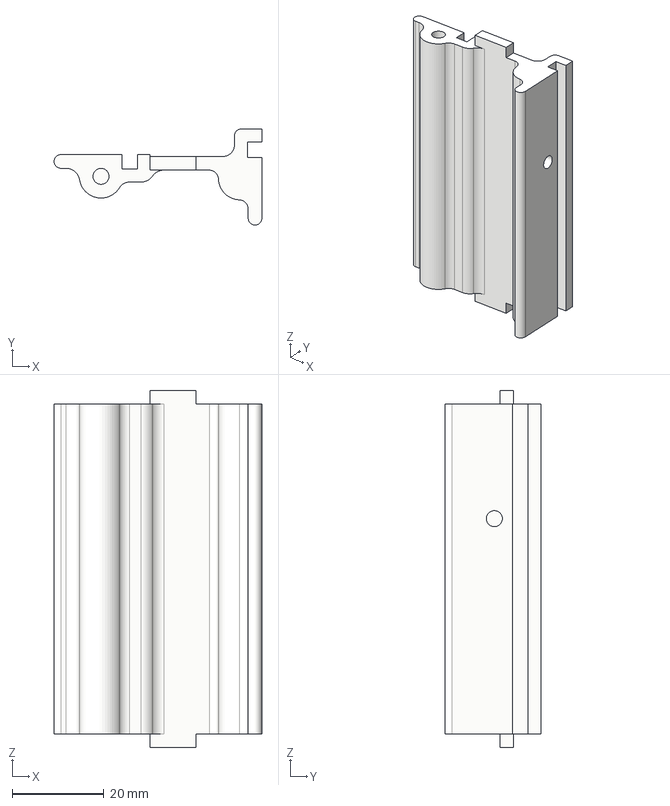
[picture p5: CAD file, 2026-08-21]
Construction/Fusion360Export/Current/Bases/BaseV7/3DPrints/SlideSupports_v3.step
45.4 x 21.0 x 78.0 mm

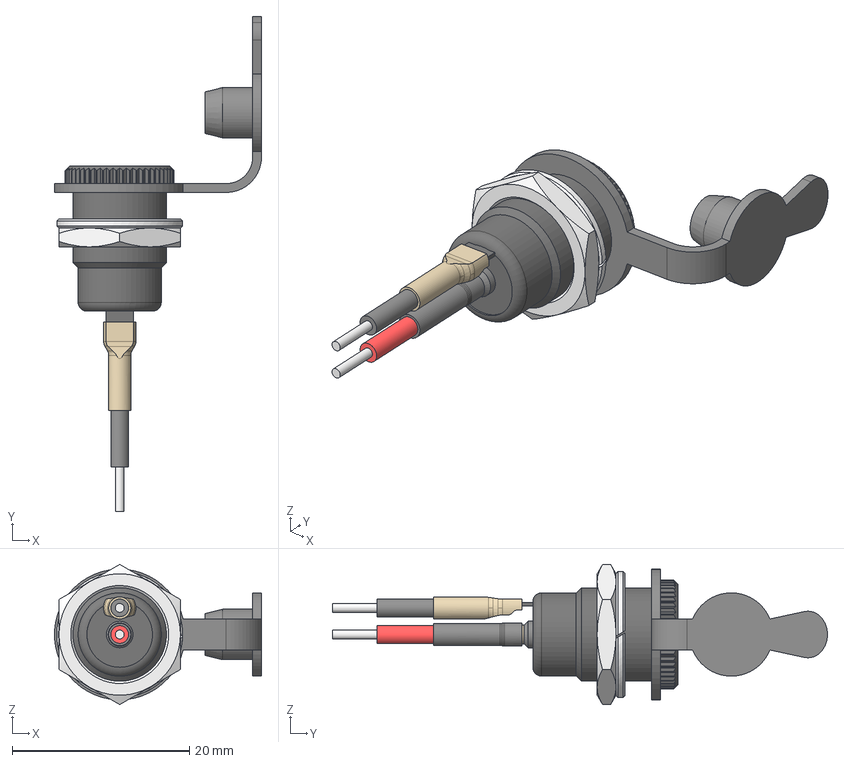
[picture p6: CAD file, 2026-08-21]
Construction/Fusion360Export/Current/Bases/BaseV7/Electronics/Jack_v3.step
23.4 x 55.9 x 15.8 mm

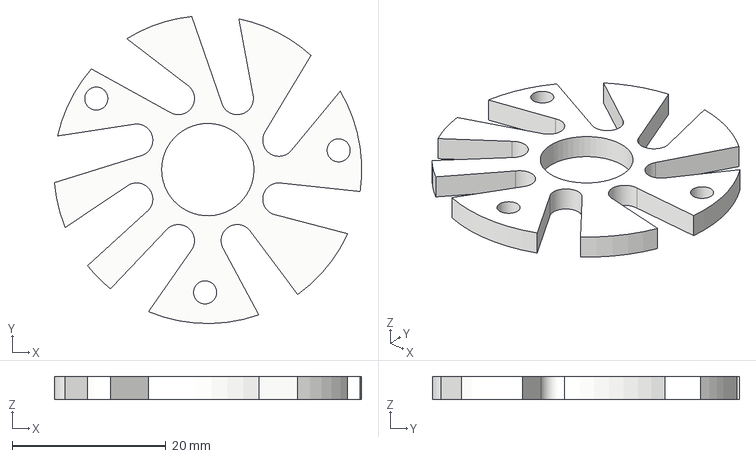
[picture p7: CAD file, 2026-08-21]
Construction/Fusion360Export/Current/Bases/BaseV7/LaserCutPieces/MidBearingMount-Bottom_v21.step
39.9 x 39.9 x 3.00 mm

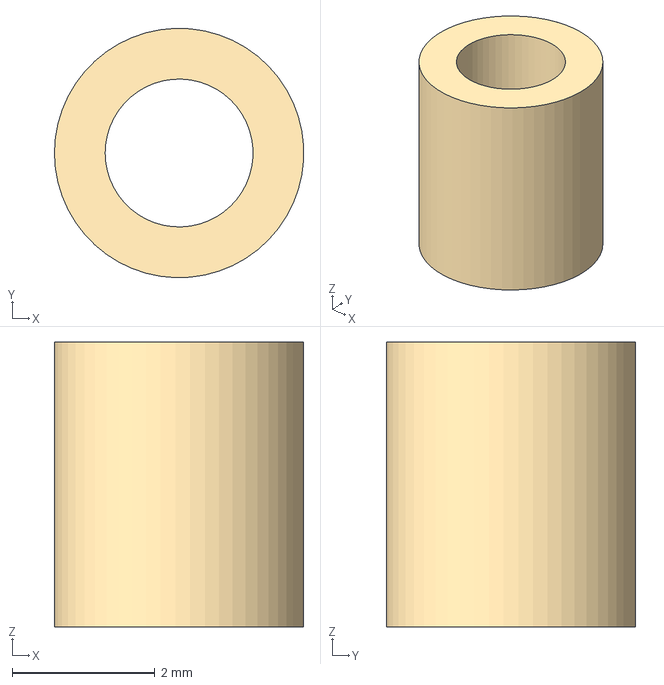
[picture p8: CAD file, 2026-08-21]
Construction/Fusion360Export/Current/Bases/BaseV7/MiscComponents/HeatSetInsert-M2.5x4_v1.step
3.50 x 3.50 x 4.00 mm

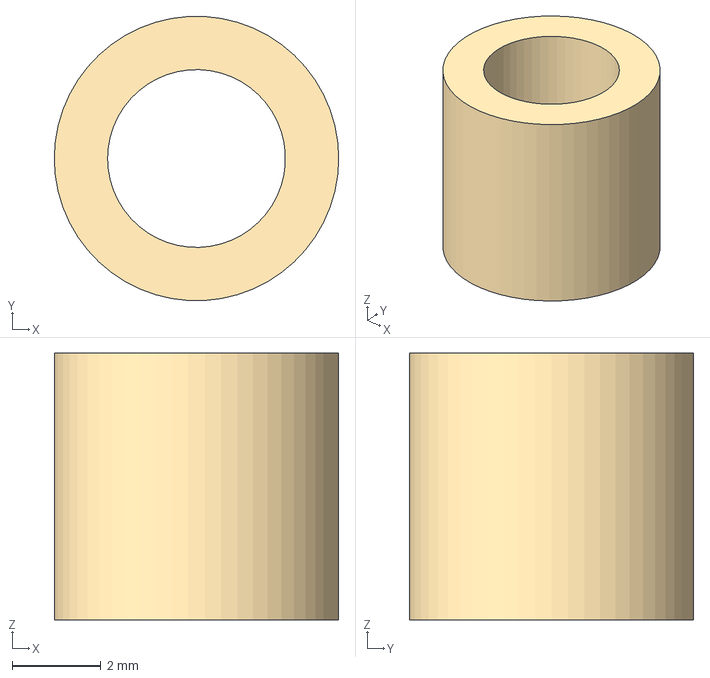
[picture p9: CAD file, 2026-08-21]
Construction/Fusion360Export/Current/FlowerHeads/FlowerHeadV3.3/Sleeve_v2.step
6.40 x 6.39 x 6.00 mm

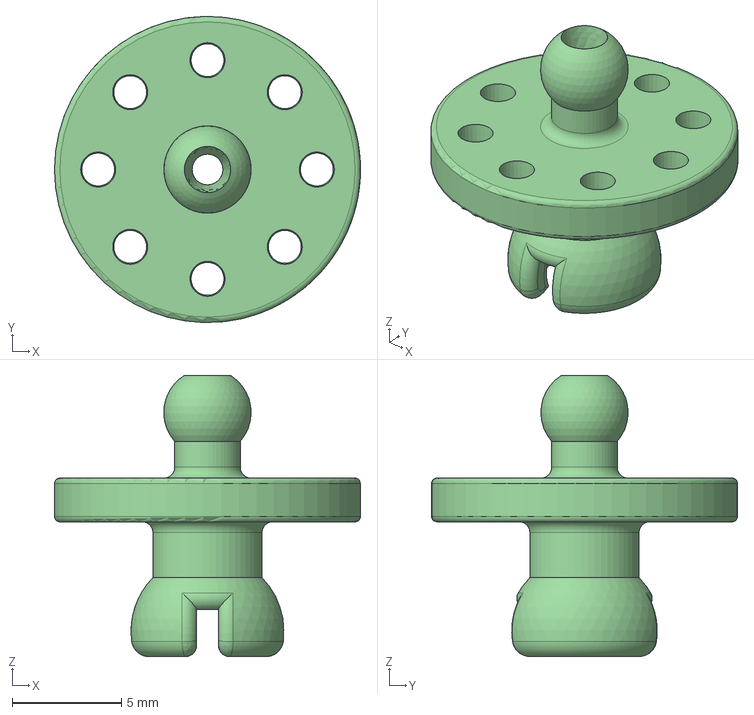
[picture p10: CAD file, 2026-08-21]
Construction/Fusion360Export/Current/Stems/ContinuumStemV4/Ball and Socket - 5mm_v2.step
14.0 x 14.0 x 12.9 mm

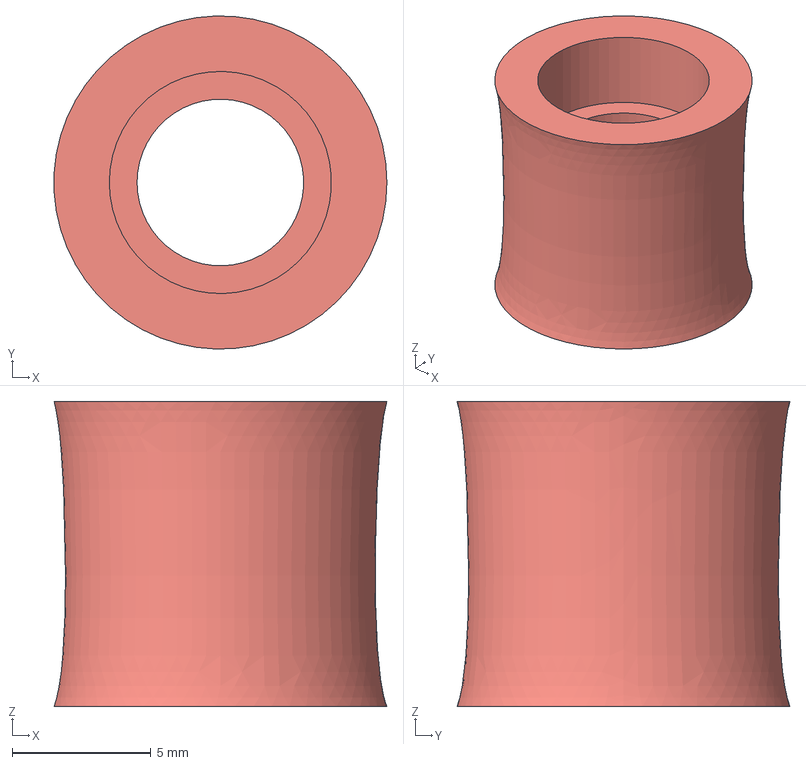
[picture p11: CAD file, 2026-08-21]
Construction/Fusion360Export/Current/Bases/BaseV7/3DPrints/BearingSleeve_v8.step
12.0 x 12.0 x 11.0 mm

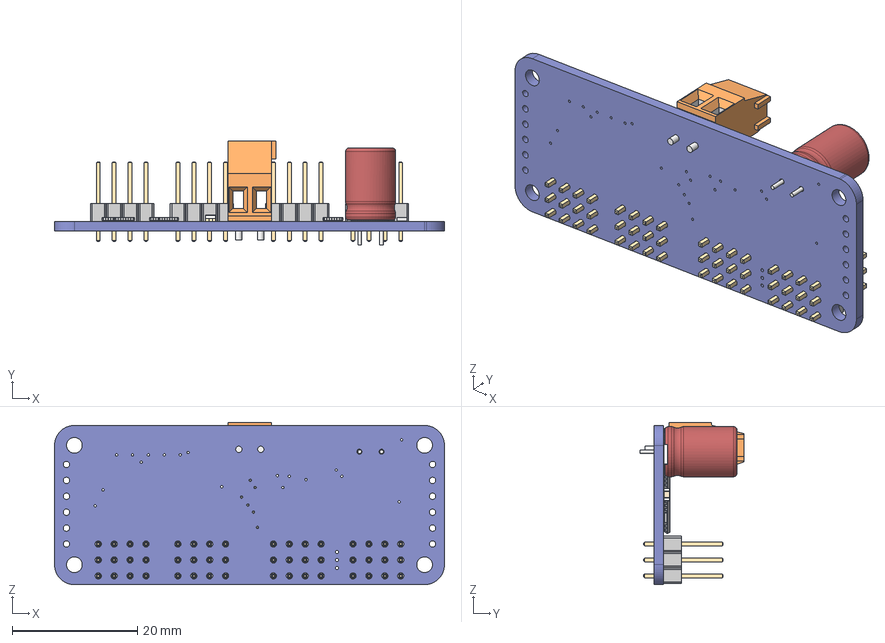
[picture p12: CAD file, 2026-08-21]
Construction/Fusion360Export/Current/Bases/BaseV7/Electronics/PCA9685_v2.step
62.2 x 16.6 x 25.9 mm
Board
Pins x 12
Case x 12
tssop_28
terminal_weidmuller_2way_1667750000
CAP_8X11.5_P3
CAT16-J4 x 6
LTST-C150KGKT_Base
LTST-C150KGKT_AnodeMark
LTST-C150KGKT_AnodeTerminal
LTST-C150KGKT_CathodeTerminal
LTST-C150KGKT_CathodeMark
LTST-C150KGKT_LedDice
LTST-C150KGKT_Lens
LTST-C150KGKT_GreenMark x 2
Pin1Body x 2
Pin2Body x 2
CeramicBody x 2
CoatingBody x 2
Case_1
Contacts

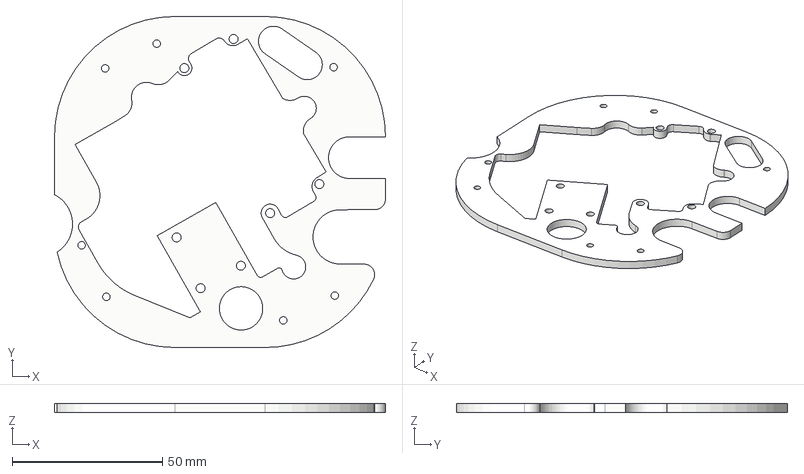
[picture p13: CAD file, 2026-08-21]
Construction/Fusion360Export/Current/Bases/BaseV7/LaserCutPieces/ElectronicsPlate_v26.step
110.0 x 110.0 x 3.00 mm

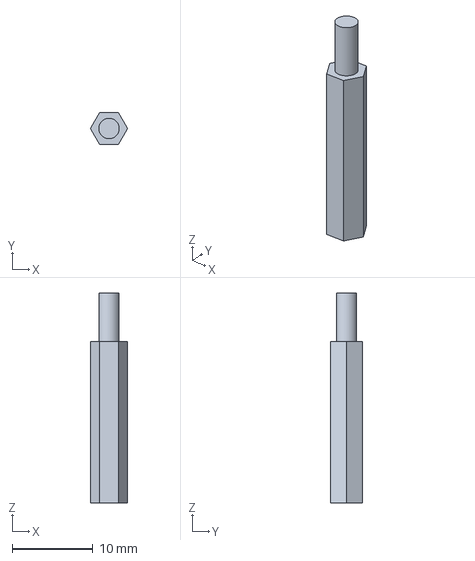
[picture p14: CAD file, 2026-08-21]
Construction/Fusion360Export/Current/Bases/BaseV7/MiscComponents/Standoff 20mm_v4.step
4.62 x 4.00 x 26.0 mm

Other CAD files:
Construction/Fusion360Export/Current/FlowerHeads/FlowerHeadV3.3/ConnectingBracketV3_v2.step
Construction/Fusion360Export/Current/Stems/ContinuumStemV4/Ball and Socket - 8mm_v2.step
Construction/Fusion360Export/Current/Bases/BaseV7/3DPrints/SpoolV2_v1.step
Construction/Fusion360Export/Current/Bases/BaseV7/Assemblies/Rollers_v4.step
Construction/Fusion360Export/Archive/Bases/BaseV0/BaseAssemblyV0_v17.f3d
Construction/Fusion360Export/Archive/Bases/BaseV0/BaseV0_v17.f3d
Construction/Fusion360Export/Archive/Bases/BaseV0/BaseV0_v17.step
Construction/Fusion360Export/Archive/Bases/BaseV0/BaseV0_v17.stl
Construction/Fusion360Export/Archive/Bases/BaseV0/CenterSupportV0_v6.f3d
Construction/Fusion360Export/Archive/Bases/BaseV0/CenterSupportV0_v6.step
Construction/Fusion360Export/Archive/Bases/BaseV0/CenterSupportV0_v6.stl
Construction/Fusion360Export/Archive/Bases/BaseV0/CenterSupportV1_v21.f3d
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

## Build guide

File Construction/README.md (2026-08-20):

# Construction

This folder contains the physical build documentation for the flower robot: the bill of materials and the laser-cut part sketches used to fabricate the chassis.

## Purpose

Everything needed to source parts and cut the structural components lives here, separate from the firmware and ROS 2 software in the rest of the repository.

## Contents

- `BOM_Aug_18_2026.xlsx`
  - Bill of materials: every purchased and fabricated part required to build the robot.
- [LaserCutSketches](LaserCutSketches)
  - SVG cut files for every laser-cut panel and bearing/rod helper, ready to send to a laser cutter.

## Notes

For engrave/cut conventions and material specs, see the [LaserCutSketches README](LaserCutSketches/README.md).

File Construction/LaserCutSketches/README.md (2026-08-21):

# LaserCutSketches

SVG cut files for the flower robot's laser-cut structural panels and rod/bearing helpers. All files are print-ready.

## Material

Designed for 3 mm acrylic sheet.

## Cut conventions

- **Red** strokes -> engrave
- **Black** strokes -> cut
- **Blue** strokes -> deep engrave 

## Files

- `LaserBasePlate.svg`, `LaserTopPlate.svg`, `LaserMidPlate.svg` - main chassis plates.
- `LaserMidPlateShell.svg`, `LaserMidPlateShellBearing.svg` - mid-plate shell and its bearing variant.
- `LaserMidBearingMount-Bottom.svg`, `LaserMidBearingMount-Mid.svg` - mid bearing mount, bottom and mid layers.
- `LaserElectronicsPlate.svg` - mounting plate for the electronics.
- `LaserServoMount.svg` - servo mounting bracket.
- `8mmRodHelper.svg`, `10mmRodHelper.svg`, `18mmRodHelper.svg` - alignment helpers for the corresponding rod diameters.

## Notes

Reference the [Construction README](../README.md) and the bill of materials (`../BOM_Aug_18_2026.xlsx`) for part quantities and further build details.

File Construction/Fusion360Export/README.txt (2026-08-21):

Archives holds incomplete and past iterations.

Current holds latest renditions. 

All current laser cut pieces cut files can be found in laser cut sketches folder

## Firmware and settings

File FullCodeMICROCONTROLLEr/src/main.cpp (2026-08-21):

// main.cpp - Firmware entry point for the ESP32 flower controller.
//
// Owns the top-level startup sequence and the main control loop: brings up
// micro-ROS/WiFi, the LEDs, servos, and N20 motor once, then on every loop
// iteration applies the latest command state (flowerData, updated by
// MicroRos.cpp's subscription callback) to the physical hardware and
// watches the ROS agent connection so it can reconnect if it drops.

#include <Arduino.h>
#include "petal_lights.h"
#include "servo_control.h"
#include "N20.h"
#include "MicroRos.h"


void setup() {
  Serial.begin(115200);

  // 1. Initialize LEDs first - they double as the connection-status indicator
  // (spin yellow while joining WiFi, spin green while finding/pinging the ROS host)
  petalLightsBegin();

  // Keep trying to connect until successful before moving on
  while (!MicroRosSetup()) {
    Serial.println("Initial Micro-ROS setup failed, retrying in 2 seconds...");
    delay(2000);
  }

  rclc_executor_spin_some(&executor, RCL_MS_TO_NS(10));
  Serial.println("Micro-ROS setup complete");
  petalLightsClear(); // Connected - drop the connection indicator before entering steady state
  delay(1000);

  // 2. Initialize I2C and PCA9685 for Servos
  servoControlBegin();
  delay(250);

  // 3. Initialize the N20 Motor (Ensures it is stopped)
  n20MotorBegin();
  delay(250);

  // Single consolidated confirmation once every subsystem is up, instead of one message per step
  send_debug("Flower node fully initialized: ROS, lights, servos, N20 motor");
  Serial.println("All system setup sucsess");
}

void loop() {
  // 1. Let micro-ROS process incoming network traffic
  rclc_executor_spin_some(&executor, RCL_MS_TO_NS(10));
  
  servoControlUpdate();

  // 2. Throttle LED and Servo updates to ~33 Hz (every 30ms)
  static unsigned long last_hardware_update = 0;
  if (millis() - last_hardware_update > 30) {
    last_hardware_update = millis();

    for (int i = 0; i < 5; i++) {
      petalLightsUpdate(i, flowerData.led_colours_hex[i], flowerData.led_colours_brightness[i]);
    }
    // flowerData.servo_angles/servo_time map directlyf to hardware channels 0-3.
    for (int i = 0; i < 4; i++) {
      servoControlSet(i, flowerData.servo_angles[i], flowerData.servo_time[i]);
    }
    petalLightsShow(); 
  }

  //3. N20 Motor Control
  n20MotorPosition();
  n20MotorControl(flowerData.n20_target_rotations, flowerData.n20_pwm);

// 4. Check Connection
  static unsigned long last_connected = 0;
  if (millis() - last_connected > 2000) {
    last_connected = millis();
    
    // If the ping FAILS
    if (rmw_uros_ping_agent(50, 1) != RMW_RET_OK) {
      Serial.println("Connection lost. Destroying entities...");
      MicroRosDestroy(); // Safe memory cleanup
      
      Serial.println("Attempting to reconnect...");
      if (!MicroRosSetup()) {
        // If the reconnect fails halfway through, we must clean up 
        // whatever partial memory was allocated before we try again next loop.
        MicroRosDestroy(); 
        Serial.println("Reconnect failed. Will try again in 2 seconds.");
      } else {
        Serial.println("Reconnected successfully!");
        petalLightsClear(); // Drop the connection indicator, back to steady state
      }
    }
  }
}

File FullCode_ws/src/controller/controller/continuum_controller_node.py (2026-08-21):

"""continuum_controller_node.py - Kinematic solver for the continuum stem.

Subscribes to /kinematic_commands ([theta1, phi1, theta2, phi2], degrees) and
converts each stage's bend into its two servos' angles, publishing the result
to /kinematic_calculated_commands for flower_mux to pick up in kinematic
mode

Also watches the (currently unused) red/blue ball vision
topics and logs whether they appear to be moving.

EXPANSION THOUGHTS:
-> If a purley forward kinematic controller is not sufficient, the ball tracking could either be used to 
    a) (easy) just check for movement, and when the backbond starts moving, then start changing the forward kinematic controller.
    b) (hard) use localization and EKF to estimate the position of the end effector, and then use that to do inverse kinematics to get the desired theta/phi values for the forward kinematic controller.


"""

import rclpy
from rclpy.node import Node
from std_msgs.msg import Float64MultiArray
from geometry_msgs.msg import PointStamped
from flower_msgs.msg import RobotCommand
import numpy as np

# --- Robot Parameters ---
# 2-stage continuum robot, antagonistic servo control -> 2 servos per stage (4 driven total).
NUM_SERVOS = 4

#Each stage's servos cover two orthogonal bending planes: S1 (lower)
# and S2 (upper) act in the XZ plane, S4 (lower) and S3 (upper) act in the YZ plane.
# The (theta, phi) bend command is therefore resolved into XZ/YZ components with
# cos(phi)/sin(phi) rather than split into a +/- antagonistic pair.
SERVO_ANGLE_LIMIT = 90.0   # deg, full physical throw of a servo either side of "straight up"
THETA_MAX = 180.0          # deg, max bend magnitude sent on /kinematic_commands
BEND_TO_SERVO_SCALE = SERVO_ANGLE_LIMIT / THETA_MAX  # maps full theta range onto full servo throw

# Servo wiring: S1/S4 actuate the lower stage, S2/S3 actuate the upper stage. The upper
# stage is mechanically mounted 45 deg offset from the lower stage's bending planes, so
# that offset is subtracted from phi2 before resolving stage 2's bend onto its servos.
UPPER_STAGE_OFFSET_DEG = 45.0


class ContinuumController(Node):
    def __init__(self):
        super().__init__('continuum_controller')

        self.kinematic_sub = self.create_subscription(Float64MultiArray, '/kinematic_commands', self.kinematic_command_callback, 10)

        self.red_ball_sub = self.create_subscription(PointStamped, '/vision/red_ball', self.red_ball_callback, 10)
        self.blue_ball_sub = self.create_subscription(PointStamped, '/vision/blue_ball', self.blue_ball_callback, 10)

        # Publishes final servo angles
        self.command_pub = self.create_publisher(RobotCommand, '/kinematic_calculated_commands', 10)

        # Latest position received from each ball's callback, check_ball_movement() needs both at once, but red/blue arrive on independent callbacks,
        # so each one is cached here and re-checked on every new message.
        self.latest_red = None
        self.latest_blue = None

        # check_ball_movement() state: last-sampled |position| for each ball and when
        # that sample was taken, used to detect movement between samples.
        self.last_red_abs = 0.0
        self.last_blue_abs = 0.0
        self.last_check_time = 0.0

    def kinematic_command_callback(self, msg):
        # Expects [theta1, phi1, theta2, phi2] in degrees, matching the Flower GUI's publisher.
        if len(msg.data) < 4:
            self.get_logger().warn(
                f"Expected 4 values [theta1, phi1, theta2, phi2], got {len(msg.data)}")
            return

        theta1, phi1, theta2, phi2 = msg.data[:4]
        servo_angles = self.compute_servo_angles(theta1, phi1, theta2, phi2)
        self.publish_servo_command(servo_angles)

    def compute_servo_angles(self, theta1, phi1, theta2, phi2):
        # Resolves each stage's (theta, phi) bend command into its two orthogonal
        # servo-plane components (XZ / YZ). 
        #
        # Stage 2 (upper) is mounted UPPER_STAGE_OFFSET_DEG rotated relative to stage 1
        # (lower)'s bending planes, so that offset is removed from phi2 first.
        phi1_rad = np.radians(phi1)
        phi2_rad = np.radians(phi2 - UPPER_STAGE_OFFSET_DEG)

        bend1_xz = np.clip(theta1 * BEND_TO_SERVO_SCALE * np.cos(phi1_rad),
                            -SERVO_ANGLE_LIMIT, SERVO_ANGLE_LIMIT)
        bend1_yz = np.clip(theta1 * BEND_TO_SERVO_SCALE * np.sin(phi1_rad),
                            -SERVO_ANGLE_LIMIT, SERVO_ANGLE_LIMIT)
        bend2_xz = np.clip(theta2 * BEND_TO_SERVO_SCALE * np.cos(phi2_rad),
                            -SERVO_ANGLE_LIMIT, SERVO_ANGLE_LIMIT)
        bend2_yz = np.clip(theta2 * BEND_TO_SERVO_SCALE * np.sin(phi2_rad),
                            -SERVO_ANGLE_LIMIT, SERVO_ANGLE_LIMIT)

        servo_angles = [0.0] * NUM_SERVOS
        servo_angles[0] = float(bend1_xz)  # S1 - lower stage, XZ plane
        servo_angles[1] = float(bend2_xz)  # S2 - upper stage, XZ plane
        servo_angles[2] = float(bend2_yz)  # S3 - upper stage, YZ plane
        servo_angles[3] = float(bend1_yz)  # S4 - lower stage, YZ plane

        servo_angles = [round(a, 6) for a in servo_angles]

        return servo_angles

    def publish_servo_command(self, servo_angles):
        msg = RobotCommand()
        msg.servo_angles = servo_angles
        self.command_pub.publish(msg)

    def red_ball_callback(self, msg):
        self.latest_red = (msg.point.x, msg.point.y, msg.point.z)
        self.check_ball_movement()

    def blue_ball_callback(self, msg):
        self.latest_blue = (msg.point.x, msg.point.y, msg.point.z)
        self.check_ball_movement()

    def check_ball_movement(self):
        # Red and blue arrive on independent callbacks, so wait until both have
        # reported at least once before trying to check anything.
        if self.latest_red is None or self.latest_blue is None:
            return

        r_x, r_y, r_z = self.latest_red
        b_x, b_y, b_z = self.latest_blue

        # Checks the balls for movement by calculating the absolute position
        red_abs = np.sqrt(r_x**2 + r_y**2 + r_z**2)
        blue_abs = np.sqrt(b_x**2 + b_y**2 + b_z**2)

        current_time = self.get_clock().now().nanoseconds / 1e9  # Convert to seconds

        # Compares the current abs position to a previous position from time (t-1) to determine if the balls are moving
        if current_time - self.last_check_time >= 0.2:  # Check per period
            if abs(red_abs - self.last_red_abs) > 0.3 or abs(blue_abs - self.last_blue_abs) > 0.3:
                self.get_logger().info("Balls are moving.")
            else:
                self.get_logger().info("Balls are stationary.")

            # Update last positions and time
            self.last_red_abs = red_abs
            self.last_blue_abs = blue_abs
            self.last_check_time = current_time
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

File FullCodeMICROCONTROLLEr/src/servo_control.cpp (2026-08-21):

// servo_control.cpp - Drives the four servos that bend the continuum
// stem. 

#include "servo_control.h"
#include "MicroRos.h"

Adafruit_PWMServoDriver pwm = Adafruit_PWMServoDriver();
ServoState servos[4]; 

// How long the intial move to current target angle takes (milliseconds)
#define INIT_EASE_MS 4000.0

// Initializes I2C and the PCA9685.
void servoControlBegin() {
    Wire.begin(SDA_PIN, SCL_PIN);
    pwm.begin();
    pwm.setPWMFreq(50);
    pwm.setOscillatorFrequency(27000000);

    servos[0].hardwareIndex = 0;
    servos[1].hardwareIndex = 1;
    servos[2].hardwareIndex = 2;
    servos[3].hardwareIndex = 3;

    unsigned long startTime = millis();

    for (int i = 0; i < 4; i++) {
        servos[i].targetAngle = flowerData.servo_angles[i];
        servos[i].targetPulse = map(flowerData.servo_angles[i], -90.0, 90.0, SERVOMIN, SERVOMAX);
        servos[i].currentPulse = servos[i].targetPulse; 
        servos[i].startPulse = servos[i].currentPulse;
        servos[i].delta_T_ms = INIT_EASE_MS;
        servos[i].startTime = startTime;
        servos[i].isMoving = false; // Stay put until a real command arrives
    }
}

// Starts a new move for one servo toward target_angle, to complete in
// delta_T_seconds.
void servoControlSet(int servoIndex, float target_angle, float delta_T_seconds) {
    if (servoIndex < 0 || servoIndex > 3) return;

    // Ignore redundant commands from the 30ms main loop
    if (abs(servos[servoIndex].targetAngle - target_angle) < 0.1 &&
        abs((servos[servoIndex].delta_T_ms / 1000.0) - delta_T_seconds) < 0.05) {
        return;
    }

    float target_pulse = SERVOMIN + ((target_angle - (-90.0)) / (90.0 - (-90.0))) * (SERVOMAX - SERVOMIN);
    target_pulse = constrain(target_pulse, SERVOMIN, SERVOMAX);

    // Start from where the servo physically is right now
    servos[servoIndex].startPulse = servos[servoIndex].currentPulse;
    servos[servoIndex].targetPulse = target_pulse;
    servos[servoIndex].targetAngle = target_angle;

    // Convert GUI seconds into Milliseconds
    servos[servoIndex].delta_T_ms = delta_T_seconds * 1000.0;
    servos[servoIndex].startTime = millis();
    servos[servoIndex].isMoving = true;
}

// Advances every servo currently mid-move by one tick: computes how far
// through its S-curve it should be given elapsed time, writes the
// interpolated pulse to the PCA9685, and marks the move finished once the
// commanded duration has elapsed. Intended to be called every loop().
void servoControlUpdate() {
    unsigned long currentMillis = millis();

    for (int i = 0; i < 4; i++) {
        if (!servos[i].isMoving) continue;

        unsigned long elapsed = currentMillis - servos[i].startTime;
        
        // Prevent Divide by Zero if GUI sends 0 seconds
        if (servos[i].delta_T_ms <= 0 || elapsed >= servos[i].delta_T_ms) {
            servos[i].currentPulse = servos[i].targetPulse; // Update location tracker
            pwm.setPWM(servos[i].hardwareIndex, 0, (uint16_t)servos[i].targetPulse);
            servos[i].isMoving = false;
        } else {
            // Your S-Curve logic 
            double progress = (double)elapsed / servos[i].delta_T_ms;
            double easedProgress = progress * progress * (3 - 2 * progress);
            
            // Keep track of exactly where we are
            servos[i].currentPulse = servos[i].startPulse + (servos[i].targetPulse - servos[i].startPulse) * easedProgress;
            pwm.setPWM(servos[i].hardwareIndex, 0, (uint16_t)servos[i].currentPulse);
        }
    }
}

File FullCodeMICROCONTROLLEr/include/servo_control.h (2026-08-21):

// servo_control.h - Declarations for the stem's PCA9685-driven servo subsystem
// (see servo_control.cpp). Servos move on a smoothed, time-based S-curve
// rather than jumping straight to a new angle.

#ifndef SERVO_CONTROL_H
#define SERVO_CONTROL_H

#include <Arduino.h>
#include <Wire.h>
#include <Adafruit_PWMServoDriver.h>

#define SERVOMIN       102   // PCA9685 pulse count at -90 degrees
#define SERVOMAX       512   // PCA9685 pulse count at +90 degrees
#define SERVO_CENTER   307   // PCA9685 pulse count at 0 degrees
#define NUM_SERVOS     16    // PCA9685 channel count (only 4 are wired/used)

#define SDA_PIN 19
#define SCL_PIN 21

// Per-servo motion state used to interpolate from startPulse to targetPulse
// over delta_T_ms, driven by servoControlUpdate() every loop iteration.
struct ServoState {
    bool isMoving = false;
    unsigned long startTime;   // millis() timestamp the current move began
    float delta_T_ms;          // Commanded move duration, milliseconds
    float startPulse;          // PCA9685 pulse count at move start
    float targetPulse;         // PCA9685 pulse count at move end
    float currentPulse;        // Last pulse count written to the driver
    float targetAngle;         // Commanded angle, degrees (for de-duplicating repeat commands)
    int hardwareIndex;         // PCA9685 channel this servo is wired to
};

void servoControlBegin();                                              // Initializes I2C/PCA9685; does not move servos, leaves them where they are
void servoControlSet(int servoIndex, float target_angle, float delta_T); // Starts a new eased move toward target_angle
void servoControlUpdate();                                              // Advances any in-progress moves; call every loop

#endif // SERVO_CONTROL_H

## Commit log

2026-05-28 Added Servo Motor Draw File
2026-05-28 Motor Testing
2026-06-04 Servo Motor test script with python controller
2026-06-30 Added new features and files for FullCodeV1 project, including N20 motor control, Bluetooth communication, and servo control functionalities. Updated platformio.ini configuration and main.cpp to inte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
2026-07-09 added framework for box breathing display
2026-07-10 general ease of life updates, but N20motor is now glitched :(
    [main.cpp]
2026-07-13 lots of little changes for the good. Inproved box breating and made servo floats rather than int8's
2026-07-14 Fixed N20 motor initilization
    [N20.cpp, main.cpp]
2026-07-14 Added Reconection abilitiy on the ESP32
2026-07-14 Added a zero for the n20 motor
2026-07-21 Added an S-curve Servo motor test to reduce jerk.
2026-07-22 BugFixes and added S curve logic to both microcontroller and GUI and ROS
    [MicroRos.cpp, main.cpp, servo_control.cpp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]
2026-07-29 updated to include cameras in launch as new cameras have arrived
2026-08-04 fully functional ball and distance tracking -> Fixed calibration issues with hard rules for brightness and exposure, added proper grid calibration squence and changed to use calibration matricies rat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
    [continuum_controller_node.py]
2026-08-05 UpdatedFlowerGUI with forward kinematics and a MUX script to go between Kinematic and manual mode.
2026-08-11 Lots of fixed changes alongside addition of resting movmenetn
    [continuum_controller_node.py, flower_gui_node.py, servo_control.cpp]
2026-08-18 Added Construction, BOM, and Laser Cut SVGS's
    [BOM_Aug_18_2026.xlsx]
2026-08-20 General Updates. Removed the neck joint and added connection states.
2026-08-21 Added CAD Files
    [1000uF 16V electr 10 x16mm -P.diameter 5mm-Black-White_v1.f3d, 1000uF 16V electr 10 x16mm -P.diameter 5mm-Black-White_v1.step, 1000uF 16V electr 10 x16mm -P.di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]
2026-08-21 Fixed the Laser cut peices to be recent
2026-08-21 added red bars to GUI and fixed BOM
    [BOM_Aug_18_2026.xlsx]

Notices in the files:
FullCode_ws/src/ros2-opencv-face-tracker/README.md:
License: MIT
